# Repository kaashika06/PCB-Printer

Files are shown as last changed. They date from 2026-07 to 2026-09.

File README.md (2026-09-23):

# PCB Printer

## Overview

This repository contains the **CAD models and mechanical design files** developed for a prototype **additive PCB printer**.

The project explores the use of **Direct Ink Writing (DIW)** to fabricate conductive traces by depositing conductive ink directly onto a substrate, as an alternative to conventional subtractive PCB fabrication.

The printer was designed around a **syringe-based piston extrusion system** and a **belt-driven X-Y motion system**, with the printhead positioning and ink deposition controlled through a GRBL-based CNC system.

---

## Project Objectives

The main objective was to develop a low-cost prototype PCB printer capable of depositing conductive ink along programmed toolpaths.

The mechanical system was designed to:

- Precisely position the extrusion head in the X-Y plane
- Control conductive ink deposition using a syringe and plunger mechanism
- Provide a modular mechanical structure for prototyping and further development
- Support future integration of curing and PCB-printing processes
- Enable rapid prototyping of custom PCB geometries

---

## System Architecture

The printer consists primarily of the following subsystems:

### 1. X-Y Linear Motion System

A **belt-driven Cartesian motion system** was selected for positioning the printhead.

The system consists of:

- Stepper motors
- Timing belts
- Pulleys
- Linear rails/rods
- Structural components

The belt drive converts the rotational motion of the stepper motors into translational motion of the printhead.

A belt-driven system was selected as a practical balance between:

- Speed
- Accuracy
- Cost
- Ease of fabrication
- Ease of implementation

---

### 2. Syringe-Based Extrusion System

The extrusion system uses a **mechanically driven syringe and plunger** to deposit conductive ink.

A stepper motor drives the plunger, allowing the amount of material being deposited to be controlled through the displacement of the syringe plunger.

The piston-based approach was selected because it provides:

- Controlled extrusion volume
- Repeatable material deposition
- Compatibility with conductive inks
- Direct control over extrusion rate

The extrusion mechanism was designed with high-viscosity conductive inks in mind.

---

### 3. Z-Axis / Extrusion Control

The Z-axis is used to drive the syringe plunger rather than simply positioning the printhead.

The extrusion motion is coordinated with the X-Y movement so that the amount of ink deposited remains consistent as the printhead moves along the PCB toolpath.

The control system therefore treats the Z-axis as an **extrusion axis**.

---

## CAD Design

The CAD files in this repository represent the mechanical components and assemblies developed during the design phase of the PCB printer.

The design includes components associated with:

- Printer frame
- X-Y motion system
- Belt and pulley arrangement
- Linear guides
- Stepper motor mounting
- Syringe extrusion mechanism
- Printhead assembly
- Mechanical supports and brackets
- Overall printer assembly

The CAD models were developed as part of the transition from the initial concept to the final prototype.

---

## Manufacturing Approach

The printer uses an **additive PCB fabrication** approach.

Instead of removing unwanted copper through chemical etching, conductive ink is deposited directly onto the substrate.

### Printing Process

```text
PCB Design
     ↓
Gerber File (.GTL)
     ↓
Toolpath Generation
     ↓
G-Code
     ↓
GRBL Controller
     ↓
X-Y Motion + Syringe Extrusion
     ↓
Conductive Trace Deposition
     ↓
Curing

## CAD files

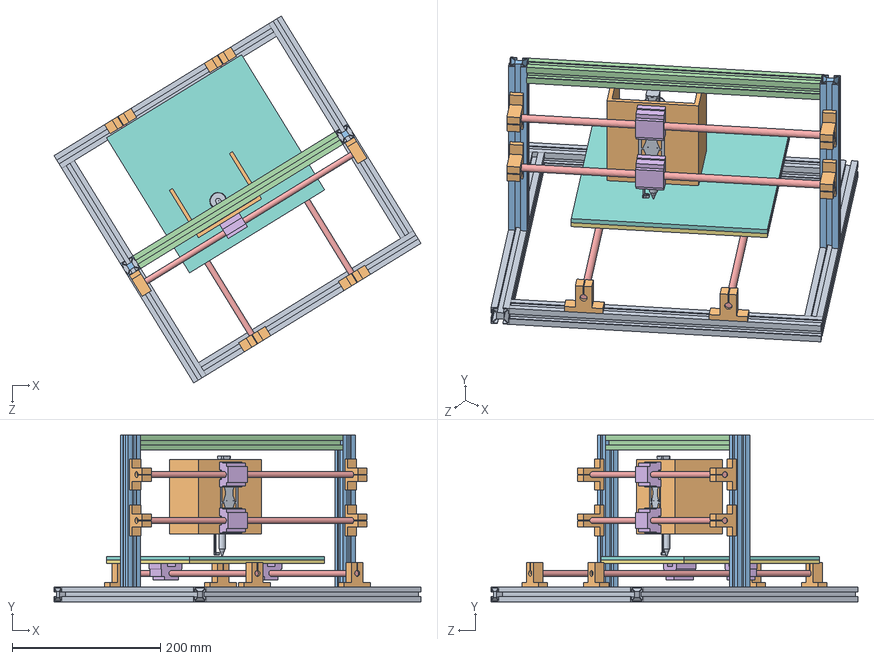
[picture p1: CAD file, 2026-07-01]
pcb_printer_frame.SLDASM
495.2 x 225.0 x 495.2 mm
T-beam Aluminium x 4
mounting block x 8
T-beam Aluminium 2 x 2
T-beam Aluminium 3
rod x 4
mount 2 x 4
heating bed
acrylic board
ext_frame

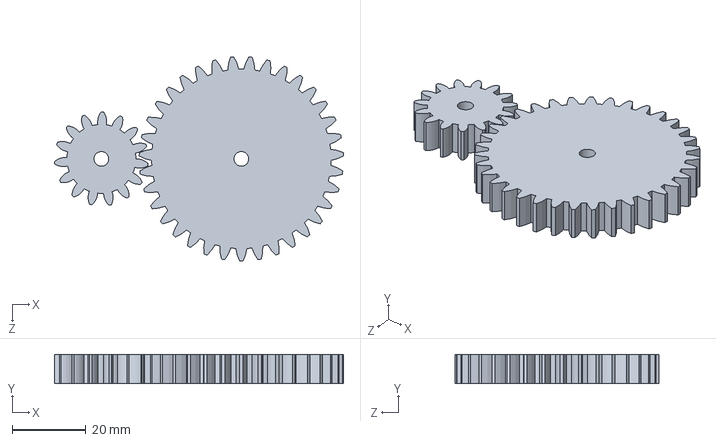
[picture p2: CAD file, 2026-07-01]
Parts/Gears_extruder.SLDASM
78.5 x 8.00 x 55.4 mm
spur gear_iso x 2

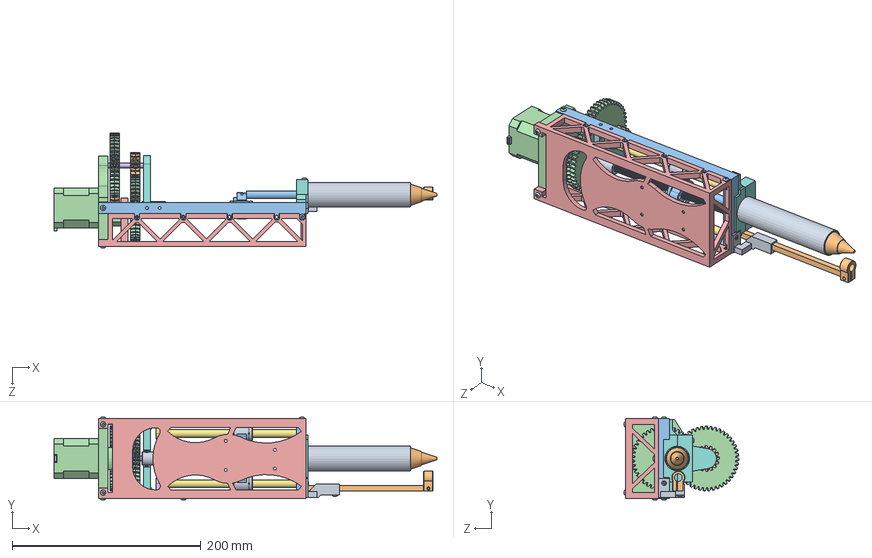
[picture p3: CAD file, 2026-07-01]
Parts/Assembly_extruder.SLDASM
405.9 x 87.7 x 121.6 mm
Shaft Coupler.stp
M4 x 4mm Cup-Point Set Screw.stp x 4
Acople_guia_lineal.stp
Barras_guia.stp x 2
Adaptador_extrusor_carro_x_superior_pieza_sup_acople_rodamiento.stp
Sujeccion embolo.stp
Engranaje chevron_V4.stp x 2
Husillo_8x2_Tr.stp
eje engranaje3 d=5,L=35.stp
Acople_guia_lineal_MIR.stp
LM8UU.stp x 2
Engranaje pi_X_F1on chevron_V4.stp x 2
tuerca HT3D Tr8x2mm.stp
eje motor nema.stp
eje engranaje2 d=5,L=51.stp
Rodamiento 625ZZ.stp x 3
Cuerpo_jeringuilla_26 mm.stp
Boquilla 0.6.stp
ISO 7380 - M3 x 6.stp x 2
ISO 7380 - M3 x 8.stp x 3
ISO 7380 - M3 x 20.stp
DIN 562 - M3 x 5.5.stp x 7
DIN 916 - M3 x 8.stp x 6
ISO 7380 - M3 x 16.stp
ISO 7380 - M3 x 16_1.stp
Insertro roscado M3.stp x 24
V_X_E1stago_jeringa_16.5 mm.stp
M 3x10.stp x 3

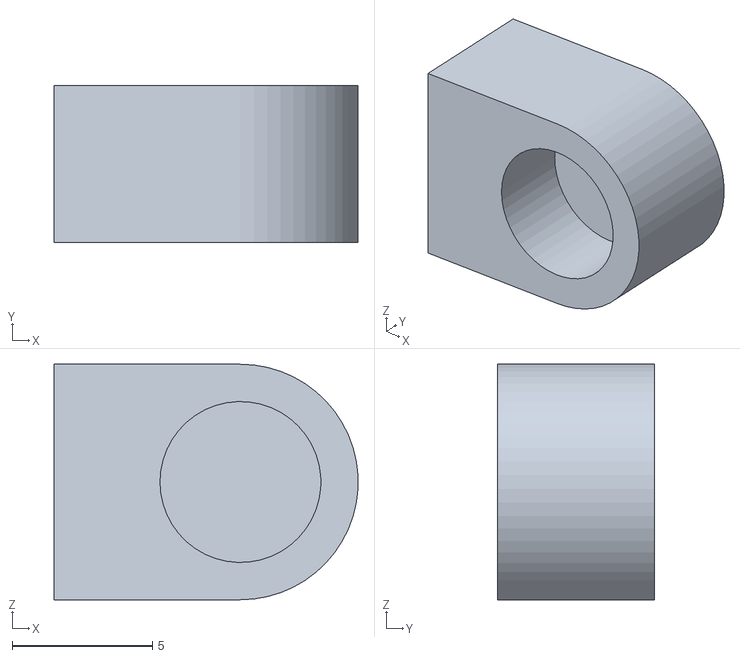
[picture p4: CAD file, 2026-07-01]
Parts/to print/Rod_bracket_2.STL
10.8 x 5.60 x 8.40

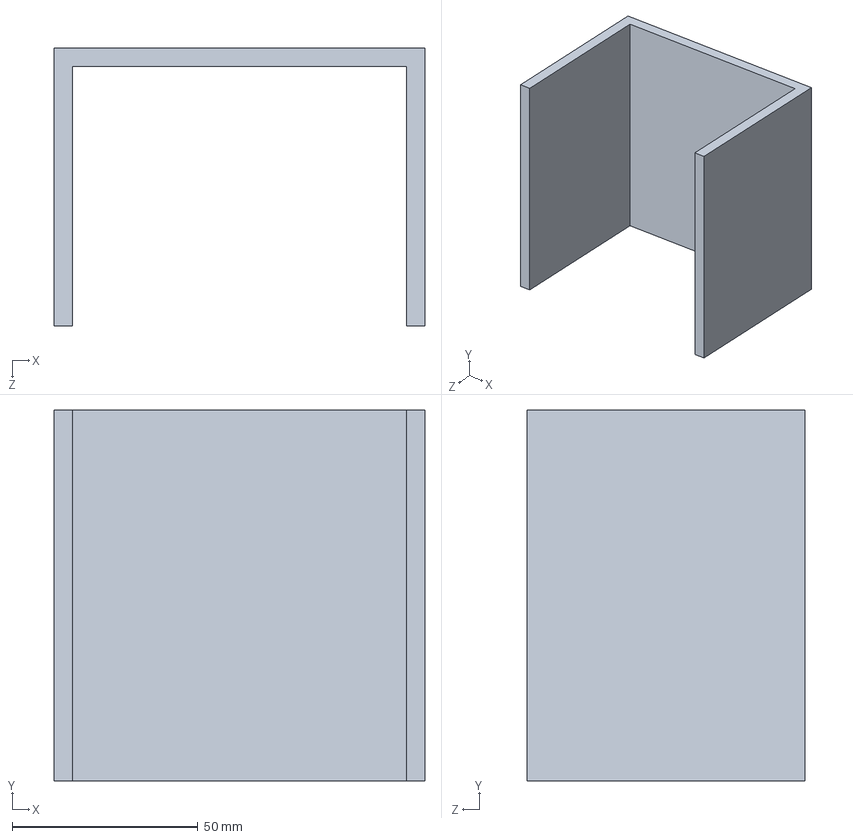
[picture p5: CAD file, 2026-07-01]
Parts/ext_frame.SLDPRT
100.0 x 100.0 x 75.0 mm

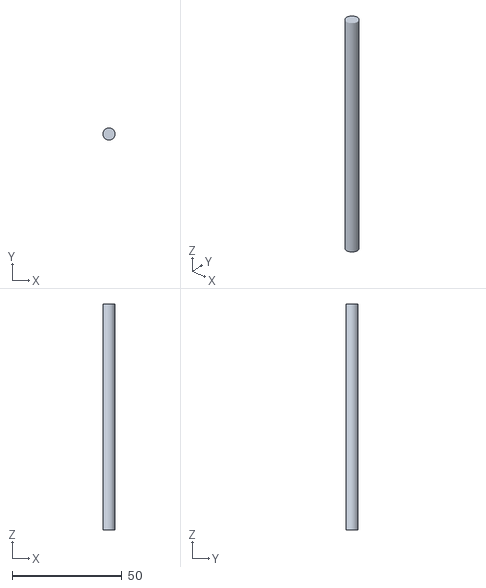
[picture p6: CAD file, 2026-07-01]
Parts/to print/Rod_linear_guide_2.STL
5.60 x 5.59 x 102.9

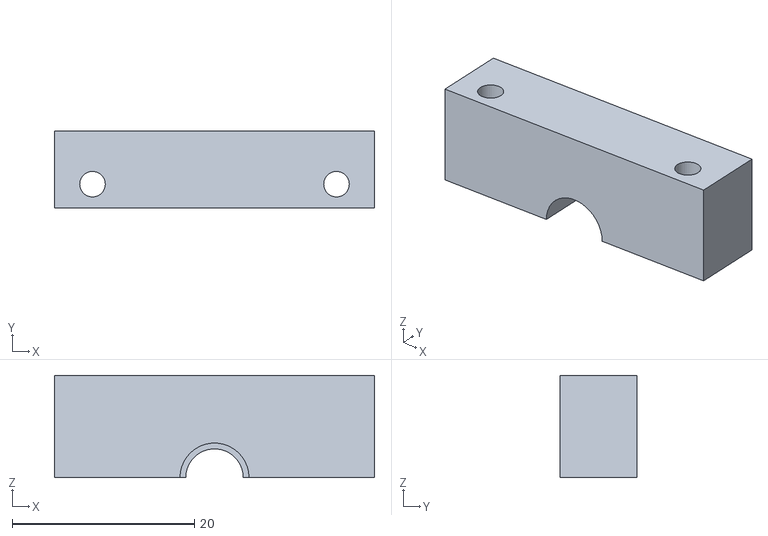
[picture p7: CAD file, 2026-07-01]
Parts/Syringe_holder_10.82mm_ext_close.STL
35.1 x 8.40 x 11.2

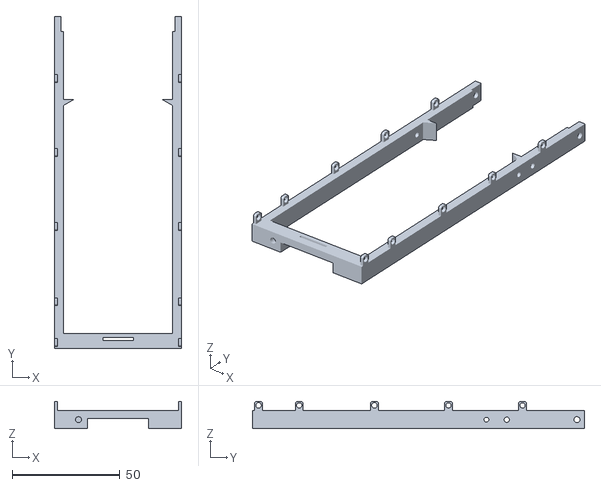
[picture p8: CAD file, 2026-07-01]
Parts/to print/Front frame.STL
59.1 x 154.0 x 12.7

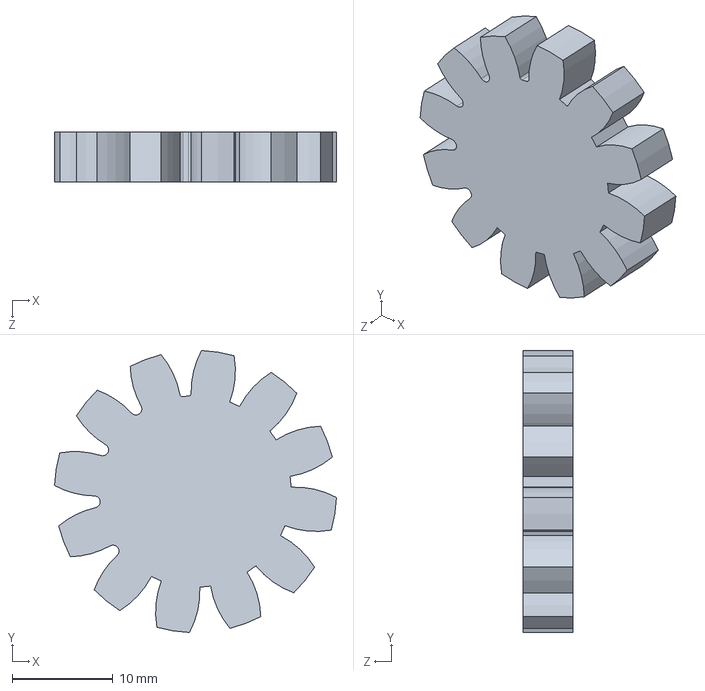
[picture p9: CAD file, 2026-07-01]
Parts/Gear.SLDPRT
28.0 x 28.0 x 5.00 mm

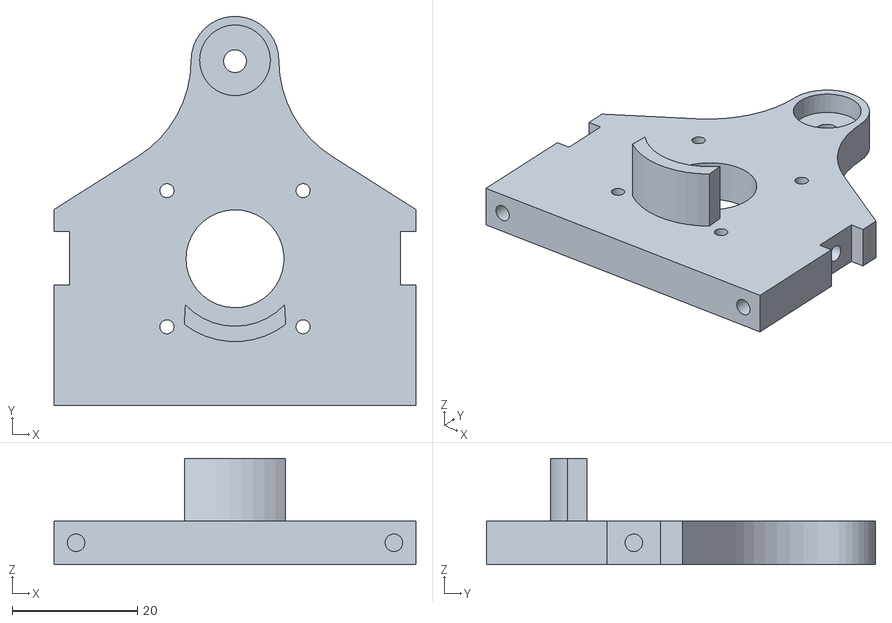
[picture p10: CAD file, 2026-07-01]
Parts/to print/Motor_base.STL
57.7 x 62.0 x 17.0

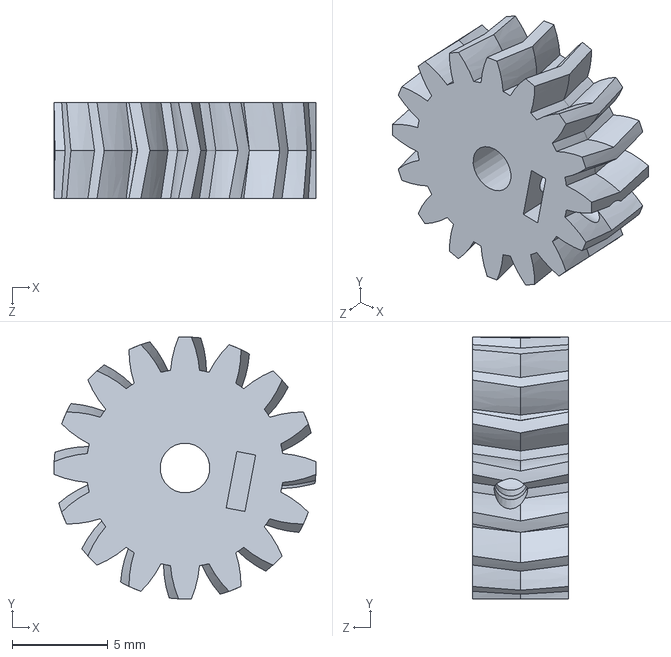
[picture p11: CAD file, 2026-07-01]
Parts/Pinion_scaled.SLDPRT
13.7 x 13.7 x 5.00 mm

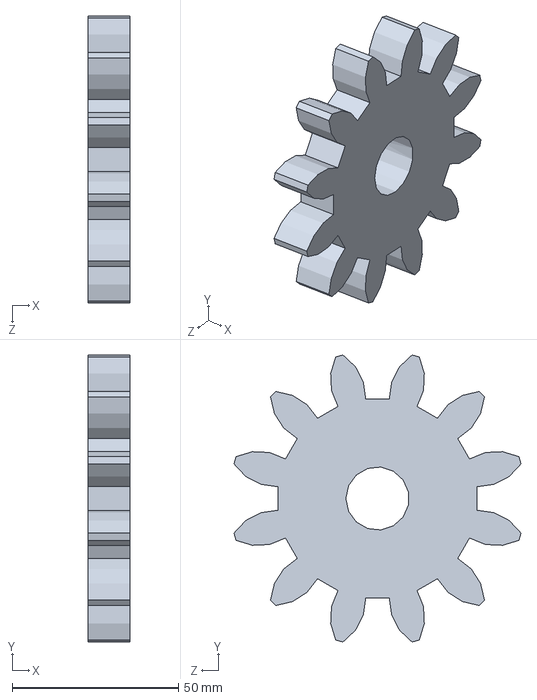
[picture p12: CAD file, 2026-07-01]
Parts/spur gear_iso.sldprt
12.7 x 86.4 x 86.4 mm

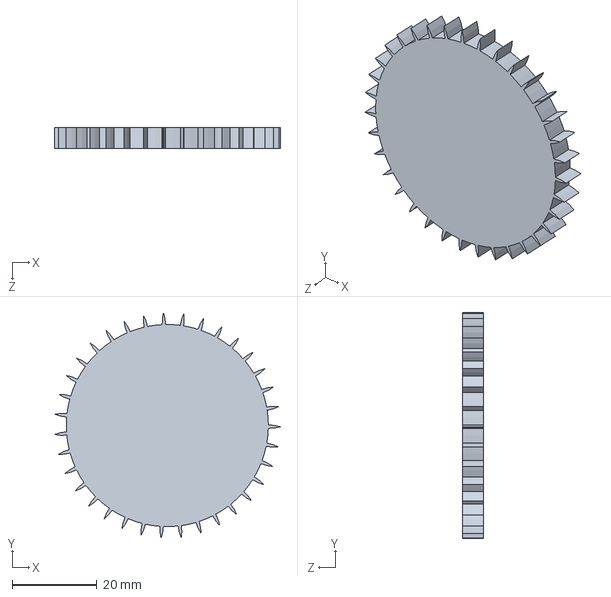
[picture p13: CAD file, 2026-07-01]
Parts/Gear_self.SLDPRT
53.4 x 53.4 x 5.00 mm

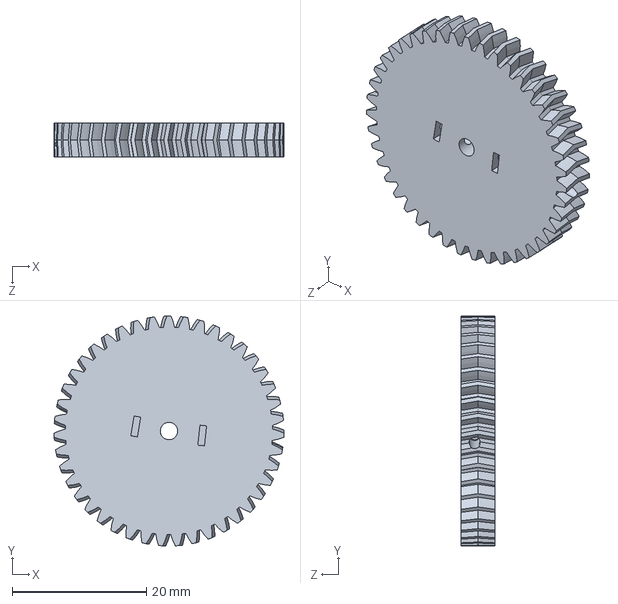
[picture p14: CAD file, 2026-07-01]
Parts/Gear 1_scaled.SLDPRT
34.3 x 34.3 x 5.00 mm

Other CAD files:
Parts/extr_assem.SLDASM
Parts/rod.SLDPRT
Parts/Gear 1 scaled.PRT
Parts/Gear 1 scaled.STL
Parts/Nut_holder.STL
Parts/Nut_holder_final.STL
Parts/Nut_holder_final.stp.SLDPRT
Parts/Nut_holder_final_final.STL
Parts/Nut_holder_final_final.stp.SLDPRT
Parts/Pinion_self.SLDPRT
Parts/Pinion_self.STL
Parts/Rod_bracket.stp.SLDPRT
Parts/T-beam Aluminium 2.SLDPRT
Parts/T-beam Aluminium 3.SLDPRT
Parts/T-beam Aluminium.SLDPRT
Parts/acrylic board.SLDPRT
Parts/ext_frame.STL
Parts/heating bed.SLDPRT
Parts/lead screw.STL
Parts/mount 2.SLDPRT
Parts/mounting block.SLDPRT
Parts/shaft for gears.SLDPRT
Parts/spindle_leadscrew.STL
Parts/to print/Nut_holder.STL
Parts/to print/spindle_leadscrew.STL

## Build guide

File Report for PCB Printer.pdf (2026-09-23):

# Printed Circuit Board Printer

~ Kaashika Chopra

# Table of Contents

Sr. No. | Topic
1. Introduction
2. Design of System | ● Extrusion System ● Linear Motion System
3. Software for PCB Printer
4. Week Wise Workflow
5. Conclusion

# Introduction

Traditionally, PCBs are made through the process of subtractive fabrication which etches copper from a board and leaves behind the trace required. 3D-printed PCBs are circuit boards created using additive manufacturing rather than traditional subtractive PCB fabrication. Specialized printers deposit conductive and insulating materials layer by layer to build the board.

Conventional PCB Manufacturing (Etching Method)

The most widely used method involves:

- Coating a copper-clad board with a resist layer
- Printing the circuit pattern using UV exposure or toner transfer
- Chemically etching away unwanted copper
- Leaving behind the desired conductive traces

Additive PCB Printing (Our Approach)

Instead of removing material, conductive ink is directly deposited onto a substrate. This is known as Direct Ink Writing (DIW), 3D-printing technique where a printer extrudes liquid or paste-like material through a nozzle to “draw” structures layer by layer. These types of PCB 3D printers lay down a conductive material to form the circuitry. These materials usually come as inks or filaments infused with conductive particles, such as silver, copper, or graphite.

- Faster prototyping
- Reduced waste
- Environmentally safer
- Suitable for flexible and custom PCBs

# Design of System

Overall, we finalised our design into the following components:

- Syringe + plunger-based extrusion system for ink deposition
- Belt-driven X-Y motion system for positioning
- Graphite based ink to use as our conductive ink
- Heating bed to cure the ink

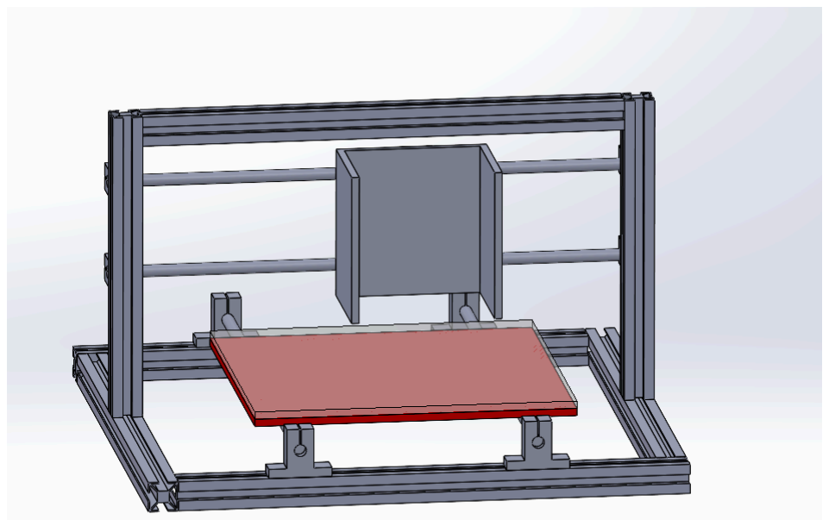
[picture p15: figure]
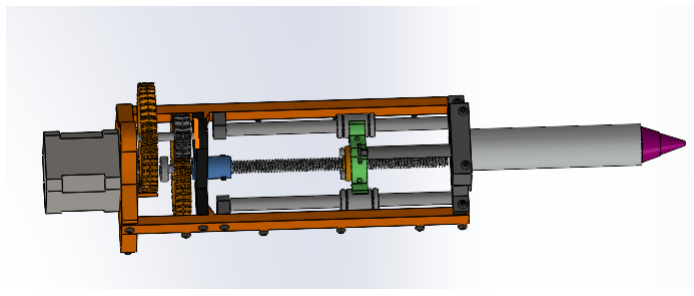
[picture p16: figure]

## Extrusion System

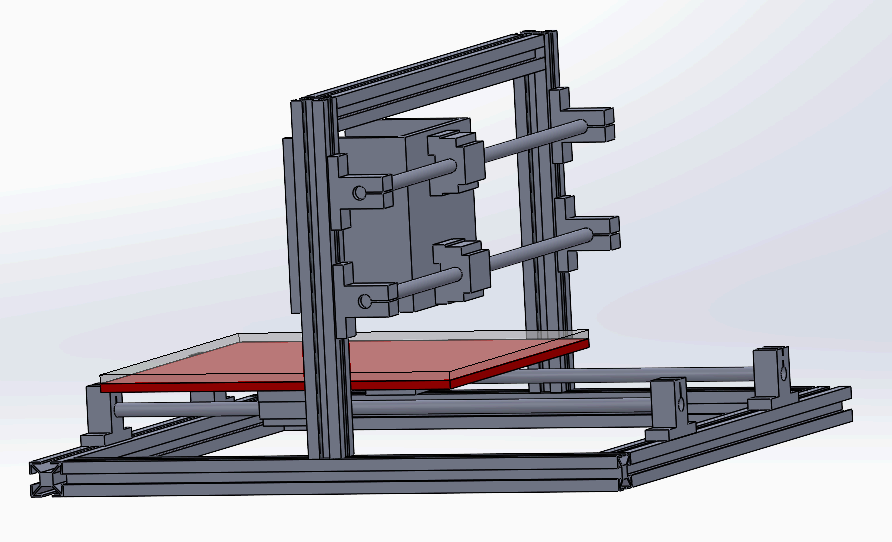
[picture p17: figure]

We explored a variety of extrusion systems for our project including:
1. Filament based extrusion of conductive filament
2. Pneumatic Extrusion system(uses compressed air to force ink through a nozzle for deposition)
3. Screw Driven extruder system(A screw-driven extrusion system uses a rotating screw mechanism to continuously transport ink toward the nozzle)

### 4. Piston based extruder system

A piston-based extrusion system uses a mechanically driven plunger, typically powered by a stepper motor and lead screw mechanism, to push ink through the nozzle.

This method provides highly accurate control over extrusion volume and flow rate, making it well-suited for applications requiring precise material deposition. It offers excellent repeatability and is capable of handling medium- to high-viscosity conductive inks commonly used in PCB fabrication.

For the design, we referred to the following research paper: Pandya, K.S., Shindalkar, S.S. & Kandasubramanian, B. Breakthrough to the pragmatic evolution of direct ink writing:

progression, challenges, and future. Prog Addit Manuf 8, 1303–1328 (2023). https://doi.org/10.1007/s40964-023-00399-7

The paper describes the procedure of DIW(Direct Ink Writing), covering the mechanisms and types of ink used for it.

## Linear Motion System

Types of Linear Motion Mechanisms
There are various types of systems we could have adopted for our motion in x-y axis. For eg:
1. Lead Screw Drive
2. Rack and Pinon Drive System
3. Linear Rail/Actuator System

### 4. Belt Drive System

After evaluating the available linear motion systems, the belt drive system was selected for the X-Y motion of the 3D printer.

This decision was made because it offers the most practical balance between speed, accuracy, cost, and ease of implementation. The lightweight design enables fast and smooth movement, which is essential for efficient ink deposition and precise path following during PCB printing.

Compared to lead screw systems, the belt drive provides significantly higher movement speed, accuracy. Lead Screw systems are mostly used for Z-axis where there is a lot of load handling. It is also simpler and more economical than rack-and-pinion or advanced linear actuator systems.

Belt Drive Mechanism

Components

- Stepper motors
- Timing belts
- Pulleys
- Linear rails/rods

Working Principle - As the stepper motor rotates, the pulley moves which is connected to the belt. The belt converts rotational motion to translational motion, and the print head moves along the axis.

# Software for PCB Printing System

The printer operates in a Cartesian coordinate system:

- X-axis: horizontal movement
- Y-axis: forward/backward movement

The specific coordinates of the printhead at any moment are specified by using G-codes. The controller interprets the commands and the stepper motors rotate accordingly. GRBL is an open-source firmware for CNC machines. It runs on microcontrollers (like Arduino) and converts G-code into motor movements.

Belts move the print head precisely, and ink is deposited at the required position.

Overall, it works as follows:

1. PCB design is created in software
2. Design converted into G-code
3. G-code sent to GRBL controller
4. GRBL drives stepper motors
5. X-Y system positions the syringe
6. Plunger extrudes ink to form traces

Understanding Gerber Files
The foundation of any PCB project is the *Gerber file* format (RS-274X). These are open-source vector files that describe each physical layer of the board. In this project, the primary file used is the Top Copper (.GTL). While traditionally used to tell a manufacturer where to leave copper on a board, in this context, the Gerber serves as a coordinate map for where conductive material must be deposited.

Traditional Milling vs. Additive Printing
The transition from subtractive to additive manufacturing requires a fundamental shift in toolpath logic:

Subtractive (Milling): The software calculates Isolation Routing. The "tool" is a physical bit that removes material around the intended traces. The G-code focuses on the empty space. Additive (Printing): The software uses Area Filling (or "Painting"). The "tool" is a dispensing nozzle that deposits material inside the trace boundaries. The G-code must account for material flow, volume, and overlap to ensure a solid, conductive path.

The Syringe-Driven Extrusion Setup

To handle high-viscosity conductive ink, the system utilizes a piston-driven extrusion mechanism controlled by a dedicated stepper motor (Z-axis). This mechanical setup necessitates specific modifications to standard CNC G-code:
➔ Fluid Dynamics & Pressure: Unlike a spinning spindle, a syringe has "pressure lag." G-code must include Priming Sequences (advancing the Z-axis before X/Y movement) and Retraction Sequences (reversing the Z-axis at the end of a trace) to prevent oozing and ensure crisp trace edges.
➔ Coordinated Motion: The Z-axis is synchronized with X and Y. The extrusion rate is calculated as a ratio of the piston’s displacement relative to the nozzle’s travel distance, ensuring a consistent volume of ink is deposited regardless of movement speed.

Overall, the Workflow can be summarised as follows:
1. Design: Export Gerber (.GTL) from CAD software.
2. Path Generation: Use FlatCAM to generate "Paint Area" geometry based on nozzle diameter.
3. Conversion: Transform standard milling commands (M3/M5) into Z-axis extrusion and retraction commands.
4. Fabrication: Execute G-code on a GRBL-based CNC Shield, where the Z-axis drives the syringe plunger to deposit conductive traces.

# Week Wise Workflow

Week 1: Assigned the project of a 2-D printer. Research on different types of 2-D printers, updated our project to PCB Printer.
Week 2: Researched on different types of linear motions, the working behind the motors. Finalised on the belt drive.
Week 3: Explored different types of extrusion systems, inks, curing methods for the inks. Week 4: Started with CAD Model for the final project.
Week 5: Tested the motors, linear motion system
Week 6: Started making a prototype of the final extrusion system.
Week 7: Overall assembly of project.

# Difficulties faced

- Non-working stepper drivers and motors: Multiple stepper motors and drivers that were provided did not work, after trying out multiple combinations, all 3 axes finally worked together. However the setup was interfered with afterwards by someone not part of the team and it led to a non working y axis during final submission.
- Loose belts: The belt drive mechanism suffered from belts that kept constantly loosening due to the heavy loads they were carrying. To compensate, a ballscrew mechanism could be used, however all the available ballscrews were already in use by others.
- Ink Viscosity: The extruder mechanism was designed keeping in mind the high viscosity (23,500 cP) as informed by the ink manufacturer. For reference, water has a viscosity of 1 cP. However, the ink that arrived was far less viscous and resembled water more than viscous fluids. By then, it was too late to change the ink deposition mechanism.

# Conclusion

The syringe-based extrusion PCB printer represents a shift from traditional subtractive manufacturing to a more efficient additive approach. By combining precise ink deposition with a belt-driven motion system and GRBL control, the system achieves a balance between cost, performance, and flexibility, making it highly suitable for rapid prototyping and experimental electronics.

The technology is still new and being researched with only a few commercially available PCB printers, which are very expensive and use their own developed inks. Hence, the project was an attempt to make an innovative prototype PCB printer which could be worked upon further and perfected to develop a low cost printer on the commercial market.
